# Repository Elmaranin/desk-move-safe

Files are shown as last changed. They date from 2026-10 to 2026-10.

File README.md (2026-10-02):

# table-controller

A standing desk with a folding flap on it. The flap has to be moved out of the
way at a particular height, so something has to notice the desk approaching
that height and stop it there.

The desk is a **Völundr X2DM-SE** with a **CL103B-G** control board. Its panel
talks to that board over a 4-wire UART, and the whole project rests on having
worked out what they say to each other.

```
docs/                 what was learned — protocol, wiring, roadmap, photos
desk-move-safe/       PRODUCTION firmware. The one job, small console
usb-uart-tools/       Python that drives the desk from a laptop, no MCU
3d-models/            printed parts
```

## Where to start

| you want to | read |
|---|---|
| build and install the thing | [desk-move-safe/README.md](desk-move-safe/README.md) |
| wire it up | [docs/wiring.md](docs/wiring.md) |
| understand the desk's protocol | [docs/CL103B-G_protocol.md](docs/CL103B-G_protocol.md) |
| try something without flashing | [usb-uart-tools/README.md](usb-uart-tools/README.md) |
| know what is next | [docs/roadmap.md](docs/roadmap.md) |

## The two traps

**The panel header's `RX`/`TX` labels are swapped.** The pin marked `RX` is the
one the panel transmits on. Trust them and both leads land on the wrong pins,
and the failure is silent in both directions while the desk carries on working.

**A board that is not proxying is a desk that cannot move.** The panel-TX wire
is cut, so everything the main board hears comes from the firmware. That is
why proxying is on at boot — and why the failure mode is a stationary desk
rather than a runaway one.

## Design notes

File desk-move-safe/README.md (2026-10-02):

# desk-move-safe

Production firmware. Keeps a standing desk from carrying a folding flap past
the height the flap has to be moved at.

It sits in the cut panel-TX wire between the desk's control panel and its
CL103B-G main board, and forwards both directions. **The panel drives the desk
exactly as it did before.** When a move would take the desk past the flap
height, this takes the bus, stops it there, runs the flap, and lets the move
finish.

For the bench rig this was worked out on — frame tracing, raw byte dumps,
cadence and coast measurement, manual injection, panel emulation — see
desk-lab, which is kept locally and not published. None of that is here.

## Documentation

- [../docs/wiring.md](../docs/wiring.md) — board, pin map, **what to cut**
- [../docs/CL103B-G_protocol.md](../docs/CL103B-G_protocol.md) — the desk protocol
- [docs/operation.md](docs/operation.md) — what it does at the desk, modes, bring-up
- [docs/commands.md](docs/commands.md) — **every console command**, and every stored parameter

## Build

Needs **Pico SDK 2.2.0** under `~/.pico-sdk` (what the Raspberry Pi Pico VS Code
extension installs) and a **FreeRTOS-Kernel** checkout pointed at by
`FREERTOS_KERNEL_PATH` (`build.sh` carries a default).

```sh
./build.sh          # -> build/desk-move-safe.uf2
./flash.sh          # build + flash over USB, no BOOTSEL button
./flash.sh -n       # flash what is already built
```

The first flash onto a board running unrelated firmware needs one BOOTSEL
press; every flash after that is button-free.

## Two things that will bite

**The panel header's `RX`/`TX` labels are swapped** — the pin marked `RX` is
the one the panel transmits on. Both leads end up on the wrong pins if you
trust them, and the failure is silent in both directions while the desk keeps
working normally. [../docs/wiring.md](../docs/wiring.md) has the photograph.

**A board that is not proxying is a desk that cannot move.** The wire is cut,
so everything the board hears comes from here. That is why proxying is on at
boot and cannot be switched off from the console, and why the failure mode is
a stationary desk rather than a runaway one.

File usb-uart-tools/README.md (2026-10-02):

# usb-uart-tools — driving the desk from a laptop

Python that talks to the desk's bus through a **USB-UART adapter**, with no
microcontroller involved. This is where the protocol work started, and it is
still the quickest way to try something without flashing anything.

The panel is unplugged and the adapter takes its place:

```
  adapter TX --[1k]--> board RX     (we send the poll and the key frames)
  adapter RX <-------- board TX     (we read the height)
  GND ---------------- GND          3.3 V logic, 9600 8N1
```

Mind the panel header's labels — `RX` and `TX` on it are swapped relative to
the panel's own role. [docs/wiring.md](../docs/wiring.md) has the detail.

| script | what it does |
|---|---|
| `poll_test.py` | streams the idle poll and prints the height. The "is anything alive" test |
| `desk_goto.py` | closed-loop positioning: `./desk_goto.py 73cm`, `--sit`, `--stand`, `--save-sit` |
| `tmc_test.py` | one UART read to the stepper driver, decoded. `--scan` tries all four node addresses. Verified against a real TMC2209 |

`tmc_test.py` talks to the **stepper driver**, not the desk, and wants its own
wiring — 115200 8N1, and the driver has a single UART pad so it is half duplex:

```
  adapter TX --[1k]--> PDN_UART     the resistor is not optional
  adapter RX <-------- PDN_UART     the same pad, directly
  GND ---------------- GND
```

You will see your own request echoed before the reply, because RX sits on the
pad we transmit into. That echo is the point: no echo means the fault is at our
end, an echo with no reply means the driver is silent, and those need completely
different fixes.

Both take `--port`; edit `CMD_PORT` at the top of `desk_goto.py` for a default.
Protocol reference: [docs/CL103B-G_protocol.md](../docs/CL103B-G_protocol.md).

> `desk_goto.py` predates most of what is now known about this desk — in
> particular that a single edge frame is a 10 mm step, and that a recall must
> be sent as exactly ONE frame. Its `preset()` streams three, which is why it
> could save presets but never recall one. Read the protocol doc before
> trusting its timings.

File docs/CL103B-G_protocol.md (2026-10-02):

# Volundr X2DM-SE — CL103B-G Controller Protocol

Complete reverse-engineered protocol for the desk control board, verified by bus
capture. Everything here was confirmed empirically during analysis, not assumed.

**Board:** `DSK_CL103B_Main_V1.2`
**MCU:** Nations Technologies N32G031 (Cortex-M0, 3.3 V, STM32-compatible SWD)
**Panel link:** detachable control panel ↔ main board over UART

---

## 1. Physical link

- **UART, 9600 baud, 8N1, 3.3 V logic.**
- 4-pin header labelled (from the panel's viewpoint) `3.3V RX TX GND`.
- The panel is the *polling master* in normal use: it sends a request every
  poll tick; the board answers with status/height.
- **Panel poll cadence: ~104 ms** (measured 102–106 ms, ≈9.6 Hz, very stable).
  A second desk measured 103–105 ms steady, with single gaps stretching to
  115 ms around a button press — the panel's key scan costs it a few ms.
  Anything replacing the panel should poll at this rate, not faster.
- Board streams height in response to being polled — by the real panel OR by any
  device that sends the poll frames. With the panel removed, a controller that
  streams the idle poll keeps the board reporting height normally.
- **Stop polling and it stops answering.** This makes silence a bad way to stop
  the desk: it takes the height stream down with it, and a reading that has
  stopped changing is indistinguishable from a desk that has stopped moving.
  Anything that needs to watch the desk must keep sending the idle poll —
  which is equally "no command" for a held move, and costs nothing.

### Header notes (this board)
- A separate 5-pin black header is the **SWD debug port** (SWDIO/SWCLK/NRST/3V3/GND),
  not a UART. Serial attempts on it see nothing — expected; SWD is silent until a
  debugger drives it.
- The `3.3V RX TX GND` header is the panel UART used throughout this document.

### ⚠️ The board's power output is switched off while the desk moves

Measured 2026-10-02: the controller board's power output port loses its voltage
for as long as the desk's motors run, and gets it back when they stop. It is not
a tap on the supply input. Anything that has to work *during* a move must not
be powered from it — see [wiring.md](wiring.md#power).

### ⚠️ The panel header's RX and TX labels are SWAPPED

Photographed on the panel PCB of this desk (`docs/desk/2026-09-22 10-57-31.JPG`):

```
   3.3V    RX      TX     GND      <- silkscreen on the PANEL
            |       |
            |       └── the panel RECEIVES here (board -> panel, height)
            └────────── the panel TRANSMITS here (panel -> board, keys)
```

So the labels name the **main board's** role, not the panel's. The pin marked
`RX` is the one the panel drives.

The main board's own header is labelled by function and is not swapped
(`docs/desk/2026-09-22 10-56-03.JPG`): `TX to panel`, `RX from panel`.

The practical consequence, and it is the trap that costs an evening:

| you want to | use the panel pin marked |
|---|---|
| **listen** to the panel's key frames | `RX` |
| **drive** the main board (replace the panel) | `RX` |
| **listen** to the board's height frames | `TX` |
| **drive** the panel's display | `TX` |

Assuming the labels are from the panel's viewpoint puts both leads on the
wrong pins at once. The failure is silent in both directions — the input
landing on an output pin is fought and never received, the output landing on
an input pin drives nothing — while the panel and board carry on over the
wires that are still intact. The desk keeps working, and nothing is heard.

---

## 2. Frame format (both directions)

```
[ sync0 sync1 ] [ len ] [ type ] [ payload... ] [ cksum_hi cksum_lo ]
     2 bytes       1        1        variable          2 bytes
```

- **Sync encodes direction:**
  - `55 AA` = **main board → panel** (status / height)
  - `AA 55` = **panel → main board** (key reports / commands)
- **len** = total frame length in bytes = `0x08` for all frames observed.
- **type** = message id (`0x02` = height report; `0x01` = key report).
- **checksum** = 16-bit **big-endian sum of ALL preceding bytes**, sync included.

Verify / generate:

```python
def cksum_ok(f):                      # f = 8-byte frame
    s = sum(f[0:6])
    return (s >> 8) == f[6] and (s & 0xFF) == f[7]
```

Both directions use identical 8-byte framing.

---

## 3. Board → panel : height report  (`55 AA`, type 0x02)

```
55 AA 08 02  HH HL  CK CK
             └──┬─┘
     14 bits of millimetres, big-endian, with FLAGS in the top 2 bits
```

**The height field is not a plain u16.** Captured while saving a preset,
checksum valid:

```text
 121.989  105.0  board 55 AA 08 02 42 F5 02 40   0x42F5 = 17141 "mm"
```

`0x42F5 & 0x3FFF` = **757**, which was exactly the desk's height at that
moment. Bit 14 is a flag the board raises around a save — most likely the
"stored / beeping" acknowledgement, since it appeared only while save codes
were going out and cleared afterwards. Bit 15 has never been observed set.

Mask with `0x3FFF` before believing a height. Reading the field raw is not a
cosmetic bug: 17141 mm handed to a closed-loop move is a desk being told it is
sixteen metres too high, and the correction is downward and fast.

- Example: `55 AA 08 02 02 CC 01 D7` → 0x02CC = 716 = **71.6 cm**
  (checksum 55+AA+08+02+02+CC = 0x01D7 ✓).
- Streamed continuously; repeats the same frame while stationary.
- During motion, roughly one frame per mm of travel.
- Display truncates to whole cm; the bus carries full mm resolution.

### Motion characteristics
- **Down is faster than up.** Descending ≈ 2–3 mm/frame; ascending ≈ 1 mm/frame
  (gravity assists the motors). Size any timing margins against the *down* speed.
- **Post-command coast:** after the last motion command the desk keeps moving
  briefly in its direction of travel — roughly 8–15 mm depending on run length
  and load. Open-loop stops must aim short; closed-loop must re-read and settle.

### Target announcement (preset pre-move)
Before an autonomous preset move, the board briefly emits height frames carrying
the **target** value (a static height differing from current) before it starts
driving. Gives ~1 s of look-ahead: you can know the destination before motion.

Captured on an RP2350 emulating the panel, after a one-frame `0x01`:

```text
   0.000       -  board 55 AA 08 02 02 E6 01 F1  height 742 mm   <- resting
                  board  ... x50 more over 5.1 s
   5.310   110.0  board 55 AA 08 02 03 08 01 14  height 776 mm   <- TARGET
                  board  ... x9 more over 0.8 s
   6.340   100.0  board 55 AA 08 02 02 E8 01 F3  height 744 mm   <- real, climbing
   6.450   110.0  board 55 AA 08 02 02 E9 01 F4  height 745 mm
```

Three things this pins down:

- The **target is announced for ~0.8–1.0 s** as a static value, then the
  stream reverts to the real height and the desk starts moving.
- **It arrives as a jump no desk could make.** Captured with the real panel:
  the desk sitting at 743 mm, one frame later the stream says 803, a second
  after that 745 and climbing for real. That +60 mm in a single frame is how
  the announcement is told apart from motion — real travel is 2–3 mm per frame
  descending and 1 ascending, so anything past about 10 mm did not happen
  mechanically. Filter on that and the announcement stops being a hazard and
  becomes the longest look-ahead this bus offers.
- Treating it as a height is briefly wrong by six centimetres: direction flips
  twice, a ceiling check thinks the desk is above the limit, and an intercept
  computes its trigger against a height the desk never occupied.
- The board sat at 742 mm for **5.3 s after the command** before announcing
  anything. A recall is not refused quickly — "nothing happened yet" needs
  several seconds of patience before it means "ignored".
- Height then advances ~1 mm per frame climbing, matching the "up is slow"
  note above.

---

## 4. Panel → board : key report  (`AA 55`, type 0x01)

```
AA 55 08 01 00  KK  CK CK
                └┬┘
              key code (byte 5; byte 4 always 00)
```

### Confirmed code table

| Code | Action | Behaviour |
|---|---|---|
| 0x00 | idle / no key | streamed constantly as poll / keep-alive |
| 0x01 | recall **stand** | one-shot; board self-drives to stored height |
| 0x02 | recall **sit** | one-shot; board self-drives to stored height |
| 0x03 | save **stand** | store current height → stand slot (5 s button hold) |
| 0x04 | save **sit** | store current height → sit slot (5 s button hold) |
| 0x05 | **down** step | one frame = -10 mm; also the press edge of 0x06 |
| 0x06 | **down**, held | must repeat every poll tick to keep moving |
| 0x07 | **up** step | one frame = +10 mm; also the press edge of 0x08 |
| 0x08 | **up**, held | must repeat every poll tick to keep moving |
| 0x0E | panel **wake** | panel coming out of sleep, as its display lights up |

### A single edge frame is a 10 mm STEP command

`0x05` and `0x07` are not markers. One frame of either, with nothing else sent
before or after, moves the desk a fixed distance. Measured on an RP2350 in the
panel-TX path, injecting exactly one frame into the stream from a standstill:

```text
  79.919   ours AA 55 08 01 00 07 01 0F  key up edge     <- one frame
  80.024   ours AA 55 08 01 00 00 01 08  key idle
  80.679  board 55 AA 08 02 02 F2 01 FD  height 754 mm   <- 0.76 s later
   ...     1 mm per frame for 1.03 s ...
  81.709  board 55 AA 08 02 02 FB 02 06  height 763 mm   <- +10 mm exactly
```

| | up (`0x07`) | down (`0x05`) |
|---|---|---|
| travel | **+10 mm** | **−10 mm** |
| latency before motion | 0.76 s | 0.75 s |
| rate during the step | 1 mm/frame | 1 mm/frame |

Symmetric in both directions, unlike a held move, where down runs 2–3 mm/frame
against up's 1. This is the panel's fine-adjust: a tap of the button steps a
centimetre.

**Consequences for anything driving this bus:**

- **A tap is never free.** Sending an edge code to "interrupt" something costs
  a centimetre of travel in that direction. Interrupting a descent with a Down
  tap asks the desk to descend another centimetre.
- **0.75 s of latency before anything happens**, which is around seven poll
  frames. Code that sends a tap and looks for movement on the next frame will
  conclude it was ignored.
- **It is a precise positioning primitive.** Ten millimetres, repeatable, no
  coast to allow for — the creep phase of a closed-loop move can use taps
  instead of timed pulses.

### The motion codes are two pairs, edge then held

```text
        edge   held
down    0x05   0x06
up      0x07   0x08
```

Both edge codes were confirmed by hand on an RP2350 tap: a single Down tap
gives `0x05`, a single Up tap gives `0x07`. That closes out the older reading
of `0x07` as an "up transient, exact meaning not pinned down" — earlier
captures only ever caught it at press edges during a held move, so it looked
like a side effect rather than a code in its own right. Read the group as
`0x05..0x08` = {down, up} x {edge, held} and nothing in it is unexplained.

Consequence for anything that watches the bus: **a tap can move the desk
without a held code ever appearing.** Logic that treats only `0x06`/`0x08` as
"the user is driving the desk" misses short presses entirely.

### 0x0E — panel wake

Emitted by the panel as it comes out of sleep and starts displaying a height,
not in response to a button. Not yet known whether the board requires it, or
merely tolerates it, before it will answer polls — which matters for
panel-free operation (§6): a controller replacing the panel may need to send
it once at startup. Untested.

### Prebuilt frames (checksums verified)

```
idle        AA 55 08 01 00 00 01 08
recall stand AA 55 08 01 00 01 01 09
recall sit   AA 55 08 01 00 02 01 0A
save stand   AA 55 08 01 00 03 01 0B     # overwrites stored stand height
save sit     AA 55 08 01 00 04 01 0C     # overwrites stored sit height
down edge    AA 55 08 01 00 05 01 0D
down (hold)  AA 55 08 01 00 06 01 0E
up   edge    AA 55 08 01 00 07 01 0F
up   (hold)  AA 55 08 01 00 08 01 10
panel wake   AA 55 08 01 00 0E 01 16
```

Note the trap in that list: the *checksum low byte* of `down (hold)` is `0E`,
the same value as the `panel wake` **key code**. A key code of `0x0E` read out
of a misaligned parse would look identical to a real panel-wake frame. The
checksum is what tells them apart, so validate it before believing any code —
`AA 55 08 01 00 0E 01 16` is a wake, and anything else ending in `0E` is not.

### Behaviour notes
- **Up / Down are HELD commands:** motion continues only while the code streams
  at the poll cadence; revert to idle (0x00) or stop sending to halt.
- **Recall presets (0x01/0x02) are one-shot, and "once" means ONE FRAME.**
  Captured from a real panel on an RP2350 tap:

  ```text
     0.000       -  panel AA 55 08 01 00 00 01 08  key idle
                    panel  ... x58 more over 5.9 s
     6.160   115.0  panel AA 55 08 01 00 01 01 09  key recall stand
     6.265   105.0  panel AA 55 08 01 00 00 01 08  key idle
  ```

  A press of the stand button puts `0x01` on the wire for exactly one frame,
  and the next poll 105 ms later is already idle. Same for sit. No edge code
  precedes it — unlike up/down, the preset buttons emit a single code — and no
  `0x0E` is involved.

  **This is the thing to get right when emulating the panel.** A controller
  that streams the recall code for several frames is not sending a tap, it is
  holding the button, and a held preset button is the *save* gesture on this
  panel. A laptop script that streamed it for three frames could save presets
  but could never recall one.

  **A single edge frame aborts an in-progress preset.** Captured end to end: a
  stand recall heading for 803 mm, one `0x07` frame injected at 749 mm, and the
  desk stopped at 764 and stayed — 39 mm short of its target. One frame is
  enough; it does not have to be held.

  The abort is not instant. From 749 the desk travelled 15 mm over 3 s,
  decelerating — visible as the height repeating each value more often as it
  slows. Size any stop-short margin against that 15 mm, not against zero.

  So autonomous moves are both *suppressible* (don't forward 0x01/0x02) and
  *interruptible* (one injected edge frame).
- **Save (0x03/0x04) is ONE FRAME, like recall.** The ~5 s button hold is a
  *panel-side* gesture: the panel times the press locally and puts a single
  save code on the wire at the end of it. How long the button was held never
  appears on the bus.

  A controller that streams the save code for five seconds instead sends ~48
  save commands, and the board stores and beeps for a good number of them —
  measured at about ten beeps for one intended save. The board beeps once per
  save it accepts, so **more than one beep means more than one frame.**

  This is the same rule that governs recall, learned twice: **the panel emits
  one-shot codes exactly once.**
- **0x07** appears at the start/edge of up-presses (a tap transient). The reliable
  motion codes are the *held* values 0x06 / 0x08; treat 0x07 as an edge marker.

### Recall drive speed (important for tracking completion)
A recall self-drives at the normal motion speed — **upward is slow (~1 mm/frame)**.
Code that waits for a recall to finish must require *sustained* stability (≥ ~2 s
of no change) after motion is seen, or a brief plateau during the slow climb can
be mistaken for arrival.

---

## 5. Electrical / tapping rules

- 3.3 V logic. The header's `3.3V` pin is **power, not signal level** — never feed
  it into a signal line; use a 3.3 V USB-UART adapter.
- **Listen-only tapping:** input pins only. Do not drive a line the panel or board
  is already driving — two push-pull outputs on one wire corrupt frames and can
  freeze the panel (observed).
- Put a **1 k–10 k series resistor** in every probe / inject lead. Reads fine at
  9600 baud but prevents a short or drive-fight from disturbing the bus.
- **To inject commands you must be the sole driver of the board's RX line:**
  either remove the panel (replace it), or man-in-the-middle it (cut the panel's
  TX so it reaches only your controller's RX; your controller's TX drives the
  board). Do not inject while the panel is still wired straight to the board.
- Single-adapter software must **serialize port access** (one lock guarding read
  and write); concurrent read+write on one pyserial port raises "device reports
  readiness to read but returned no data" on macOS.
- Power the controller from ONE supply (its own USB, or the board's 5 V — not both);
  share ground.

---

## 6. Panel-free operation (replace the panel)

Confirmed working: a controller that streams the idle poll keeps the board
reporting height, so the panel is not required.

- **Poll continuously at ~104 ms** with the idle frame so height keeps flowing.
- To move: stream UP / DOWN at the poll cadence; stop by reverting to idle.
- To recall: send the one-shot recall frame, then track the self-driven move.
- Reading height back and closed-loop positioning both work with the panel absent.

---

## 7. Duty cycle, sleep, and the other things the manual documents

From the Völundr X2DM-SE manual (`docs/desk/2026-07-07 18-11-27.JPG` and
`18-11-37.JPG`). None of this is on the bus, but all of it changes how the bus
behaves.

### Thermal protection
**4 minutes of continuous running inside an 18-minute window** trips it — not
the "2 min on / 18 min off" estimated earlier. The display shows `HOT`, every
panel function is blocked and the buttons stop responding. It clears by itself
after 18 minutes, or on a power cycle. A lockout refuses the physical panel
too, which is how it is told apart from a logic bug.

### Energy-saving mode — and it ignores movement
After **30 seconds with no button press** the panel's display goes dark and the
controller drops to low power. Any button wakes it. The manual is explicit:

> **In energy-saving mode, movement commands are not executed.**

This matters for anything driving the bus. A controller that has been streaming
idle polls for a while and then sends a move may have that move ignored, with
the frame serving only to wake the desk. It is the most likely explanation for
the **~0.75–1.0 s** measured between an injected step frame and any movement
(§4) — the first frame wakes, the desk acts after. Untested: whether idle poll
frames count as activity and hold sleep off, or whether only key codes do.

**A move injected toward the board does not wake the panel's display.**
Observed 2026-10-02 with desk-move-safe's `go`: the desk moved and the board
kept sending height frames on the uncut height wire, but a sleeping panel stayed
dark throughout. Woken by one of its own buttons first, it followed the move
correctly. The panel's sleep is decided by the panel's own key presses; nothing
sent to the board changes it. Waking it from firmware would mean driving the
panel's `TX`-marked pin, which needs that wire cut first.

### Child lock
`stand + sit + ▲` held 5 s shows `LOC` and blocks raise/lower;
`stand + sit + ▼` held 5 s releases it. Worth knowing before concluding the
desk is ignoring the bus.

### Error codes
On error: 2 beeps, then lockout; 2 beeps again when it clears.

| | | | |
|---|---|---|---|
| `E01` motor 1 open | `E02` motor 2 open | `E03` motor 1 overload | `E04` motor 2 overload |
| `E05` motor 1 Hall unplugged | `E06` motor 2 Hall unplugged | `E08` obstacle detected | `E09` large position discrepancy |
| `E10` high voltage | `E11` low voltage | `E12` motor 1 Hall open | `E13` motor 2 Hall open |
| `E14` overload protection | | | |

Most clear with the Down button held 5 s, or a power cycle. Whether any of
these appear on the UART is not known — the height field's flag bits (§2) are
the obvious place to look.

## 8. Settings menu (P00–P06) — what can be changed in the desk itself

Hold `▼ + ▲` for 5 s to enter. `▲`/`▼` steps through P00…P06, the **stand**
button enters and confirms a parameter, and 5 s of inactivity saves and exits.

| Menu | Param | Range | Default | Notes |
|---|---|---|---|---|
| Units | `P00` | 0/1 | 0 | 0 = cm, 1 = inches |
| Min height | `P01` | 73 cm … (P02−10) | 73 cm | 1 cm steps |
| Max height | `P02` | (P01+10) … 122 cm | 122 cm | 1 cm steps |
| Tabletop thickness | `P03` | 0.0 … 10.0 cm | 0.0 | offsets the displayed height |
| Rise sensitivity | `P04` | 0–10 | 5 | obstacle protection; 0 = off, **higher number = less sensitive** |
| Descent sensitivity | `P05` | 0–10 | 5 | as P04 |
| **Buzzer** | `P06` | 0/1 | 1 | **0 = off except alarms** |

Three of these are directly useful to a project that drives the bus:

- **`P06 = 0` silences the beep.** The desk beeps once per one-shot code it
  accepts, which is unavoidable on the wire — but it does not have to be
  audible. Alarms still sound.
- **`P01`/`P02` are the desk's own travel limits**, and they are what
  `DESK_MIN_MM` / `DESK_MAX_MM` should mirror. Defaults are 730–1220 mm.
- **`P03` shifts the displayed height.** If it is non-zero, the number on the
  bus and the physical height of the top differ by that much. It was 0.0 on
  this desk.

### Confirmed: a short press is 10 mm

The manual states it outright — short press on `▲`/`▼` raises or lowers by
**10 mm**, long press moves continuously. That is the same 10 mm measured on
the wire for a single `0x07`/`0x05` frame (§4), from the other direction.

### Reset / calibration
Needed if the displayed height stops matching reality, or a leg is replaced.
Hold `▼` 5 s → display shows `RST`; press `▼` again to run it. The desk drives
to its lowest point, rises 10 mm, beeps, and shows the minimum height.

---

## 8. Positioning approach (open-loop coast → closed-loop creep)

Because of post-command coast, reliable positioning uses two phases:

1. **Coarse:** drive fast toward the target, stop short by the coast distance
   (~15 mm) so momentum carries in. Skip this phase entirely if the move is
   smaller than the coast distance (otherwise the desk overshoots or no-ops).
2. **Creep:** short pulses (≥ ~2 poll periods each ≈ 0.22 s) with a re-read
   between each, approaching at near-zero speed until within a few mm. No coast;
   works for moves of any size and cleans up the final error.

Report the settled height only after the desk is stably quiet, and take a final
fresh reading so it matches what the next command will see (accounts for coast).

### Key parameters (this desk)
- Poll / command cadence: **0.104 s**
- Coast allowance: **~15 mm** each direction (tune per run length)
- Creep pulse: **~0.22 s** (≥ 2 poll periods)
- Settle: require ~1.2 s continuous no-change; presets need ≥ 2 s after motion

---

## 9. Complete command summary (copy-paste)

```
Link:   9600 8N1, 3.3V, poll every ~104 ms
Frame:  55AA/AA55 | 08 len | type | payload | 16-bit BE sum over all prior bytes

Board→panel (55 AA):
  type 0x02  height = u16 BE mm

Panel→board (AA 55, type 0x01, code in byte 5):
  0x00 idle      0x01 recall stand   0x02 recall sit
  0x03 save stand 0x04 save sit
  0x05 down edge  0x06 down(held)     0x07 up edge   0x08 up(held)
  0x0E panel wake

Prebuilt AA 55 frames:
  idle  aa5508010000 0108      recall stand aa5508010001 0109
  recall sit aa5508010002 010a save stand aa5508010003 010b
  save sit  aa5508010004 010c
  down  aa5508010006 010e      up  aa5508010008 0110
  down edge aa5508010005 010d  up edge aa5508010007 010f
  panel wake aa550801000e 0116
```

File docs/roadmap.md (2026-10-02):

# Roadmap

Where this rig is going, and what each step has to prove before the next one is
worth starting.

## Phase 0 — done, on other hardware

- The desk protocol is reverse-engineered and bus-verified:
  [CL103B-G_protocol.md](CL103B-G_protocol.md). Framing, height reports, the
  full key-code table, injection rules, panel-free operation.
- Stepper and MT6835 encoder are proven on the bench rig at
  `../test/nema_MT6835`: motion profile, measured gearbox ratio, lost-step
  detection, encoder-defined travel limits.
- The sniffer firmware exists and is listen-only by construction.

What is *not* proven: the stepper and the encoder on the RP2350 Supermini, and
the flap against the real desk.

## Phase 1 — listen, and move the flap

*Bus half done, flap half not started.* The taps work against the real desk:
height and keys decode, the trace and the `bus` measurements run. The stepper
has not been wired to this board yet, so steps 3–5 below are still open, and
the timing question they answer is still open with them.

Wire the taps and the driver per [wiring.md](wiring.md); leave the encoder
unfitted. The desk keeps its panel and stays in charge throughout.

**Steps**

1. Ground tap + board tap only. `p` shows a live height; `w` streams it while
   the desk moves. Nothing else matters until this works.
2. Add the panel tap. Press keys, watch them decode.
3. Add the driver with the motor *uncoupled*. `home`, then `x` / `c` by hand.
4. Couple the flap. Find the real hysteresis band with `th` + `w`, then bake it
   into `FLAP_EXPAND_BELOW_MM` / `FLAP_COLLAPSE_ABOVE_MM`.
5. `auto on`, and drive the desk around for a while.

**The measurement that decides phase 2.** On the numbers currently in
`board_config.h` a full flap swing is about **2 s** — 90° of output through
48.435:1 at 1/8 microstepping is 19 400 microsteps, and at 10 000 steps/s that
is 1.94 s plus the ramp. The desk descends at roughly 25 mm/s and coasts 8–15 mm
after the last command. So by the time the flap has finished moving, the desk
has travelled something like **50 mm** past the height that triggered it, plus
coast.

(Confirm the ratio first: `GEAR_RATIO` here is 48.435, the *old* gearbox. The
bench rig now runs 17.23:1, which would cut the swing to ~0.7 s and the margin
to ~20 mm. Which box is on the flap changes the answer by a factor of three, so
measure before trusting either number.)

That number is the whole question. Time the flap and the desk for real, then:

- If the threshold can lead the collision point by that margin and still sit
  inside the desk's useful range — **listening is enough, and phase 2 is
  optional.** Preset recalls even announce their target about a second ahead
  (protocol §3), which buys more lead than a manual hold does.
- If the margin does not fit, the flap has to be able to *stop the desk*, which
  is phase 2.

**Exit criteria:** height decodes with no checksum errors over a long run, the
flap tracks the band without oscillating, and the timing above is a measured
number rather than an estimate.

## Phase 2a — replace the panel  — **done and working**

Panel unplugged, RP2350 in its place: `emul on` streams the poll at 104 ms and
the board reports height with no panel attached. `go`, `sit`, `stand`, `save`
and raw `key` all work. No rewiring was needed — GP5 is the panel tap while
sniffing and a PIO transmitter while emulating, because the wire the board
listens on is the wire the panel used to drive.

Four things the real desk taught us here, all now in
[the protocol doc](CL103B-G_protocol.md):

- **One-shot codes are sent exactly once.** One frame for a recall, one for a
  save. The panel's press durations — a tap, a five-second hold — are timed
  *inside the panel* and never reach the bus. Streaming a recall for three
  frames is why a laptop script could save presets but never recall one;
  streaming a save for five seconds stores it about ten times.
- **The height field is 14 bits plus flags.** Bit 14 is raised around a save.
  Read raw, it reports a 17-metre desk, which a closed-loop move would try
  hard to correct.
- **`0x05`/`0x07` are the down/up press edges**, completing the motion group.
- **A recall takes its time**: ~5 s before the board reacts at all, then ~1 s
  announcing the target as a static height before it starts driving.

## Phase 2b — man in the middle: **ruled out**

Splitting the panel's TX from the board's RX needs a break in that wire, and
on this desk the header cannot be passed through — there is no way to get
between the panel and the board without cutting. So a true MITM is off the
table, and with it the ability to *suppress* what the panel sends.

**Frame-gap injection does not rescue it either.** The idea — transmit in the
~95 ms the line sits idle between panel frames — is sound in timing and wrong
in electronics. The panel's TX is push-pull and actively drives the line high
when idle. Sinking against it gives a divider of roughly equal output
impedances, so the line lands near 1.6 V: not a valid logic low, so the board
does not read our bits, while both output stages pass tens of milliamps. There
is no series resistor that fixes this — one large enough to be safe makes the
panel win by more.

Either the wire is broken or we cannot talk over the panel. Those are the only
two states.

### What replaces it

Nothing needs to. The two jobs the flap actually has are both reachable
without cutting:

**Knowing early.** Three lead-time signals are already on the taps, passively:

| Signal | Lead time |
|---|---|
| a key frame (`0x05`/`0x06` down, `0x07`/`0x08` up) | the instant the user presses, before the height has moved |
| a preset recall's target announcement | ~5 s of board silence, then ~1 s of announced target, before motion |
| the height stream itself | continuous, ~1 mm per frame |

The flap currently waits for the *height* to cross a threshold, which is the
last and latest of the three. Triggering on intent instead is a firmware
change and buys back most of the swing time.

**Not needing to stop the desk.** Phase 2a already proved the RP2350 can *be*
the panel. With the panel unplugged for good, the desk only ever moves when we
tell it to — so the flap goes first and the desk follows, and there is nothing
to stop. The cost is the physical buttons, which GP12–GP15 and GP26–GP29 are
free to replace.

Cutting one wire stays available as the fallback, and is genuinely small — but
it should be the answer only after the timing measurement in phase 1 says the
lead time above is not enough.

## Phase 3 — close the flap loop with the encoder

Fit the MT6835 on GP8–GP11 and port `task_encoder.c` / `limits.c` from the
bench rig.

This is what makes the limit switch redundant: the MT6835 is absolute, so the
flap knows where it is at power-on with no homing sweep at all. Travel ends
become stored angles (`lim min` / `lim max`) instead of a switch, and a stall
becomes a number instead of silence — open-loop step/dir emits the same pulses
whether or not the motor followed them.

Bring the gearbox ratio over by *measuring* it with `cal`, not by copying
`GEAR_RATIO`: the bench rig's box measured 17.23:1 and the one before it,
sold as "50:1", measured 48.435:1.

**Exit criteria:** no homing sweep at boot, position correct after a power
cycle, and a deliberately jammed flap reports lost steps instead of silently
drifting.

## Phase 4 — permanent install

- Power from a 24 V → 5 V buck into the `5V` pad, USB disconnected — see the
  power section in [wiring.md](wiring.md) about not doing both at once.
- The onboard WS2812 on GP16 becomes the status light: height streaming,
  height stale, flap moving, fault.
- Connectors and strain relief on the desk tap. A tap that falls off mid-move
  is the failure mode most likely to happen twice.
- Enclosure, and the 3D-printed parts in `3d-models/`.

## Deliberately not planned

- **TMC2209 UART.** Both hardware UARTs belong to the desk; the driver's UART
  would have to be a PIO one. Worth it only if software current control or
  StallGuard turns out to be needed, and phase 3 makes StallGuard largely
  redundant.
- **Driving the desk to positions.** `usb-uart-tools/desk_goto.py` already does
  closed-loop positioning from a laptop. Putting it in the firmware is a
  different project from "flap follows desk".

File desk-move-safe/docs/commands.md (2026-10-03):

# Console commands

The complete command reference for the USB console (USB CDC; any terminal).
`?` prints the short form on the board.

> **Kept in sync by the build.** Every command `help()` prints in
> [`../src/console.c`](../src/console.c) must have a row in the command tables
> below, with the same signature, and every parameter in
> [`../src/params.c`](../src/params.c) must have a row in
> [Stored parameters](#stored-parameters) — and nothing may be documented that
> no longer exists. [`../tools/check_commands.sh`](../tools/check_commands.sh)
> runs at the start of `./build.sh` and fails the build on any difference.

## How the console is laid out

A few words at the top level. Everything else sits under a **group word** —
`desk`, `debug`, `lim`, `mot`, `tmc`, `enc` — and every stored value is read and
changed with **`eeprom`**. A group word on its own prints that group's state.

**Mode** says where a command works. *working* commands are available after
every reboot. *dev* commands need `dev start` first; they drive something
directly, poke a register or change the flap's stored range. See
[operation.md](operation.md#working-mode-and-dev-mode).

## Top level

| Command | Mode | What it does |
|---|---|---|
| `status` | working | Everything at a glance: the self-check (mode, driver, encoder, limits, and whether the desk is locked), then what `desk` prints, whether the settings came from flash, and the motor's state. Printed at boot too. |
| `calibrate` | working | Calibrate the flap, step by step: clears the calibration (what `reset` clears), then asks for the flap at its expanded end and at its collapsed end and stores each on `done`. Unlocks `mot` and `enc` while it runs. See [Calibrating](#calibrating). |
| `done` | working | During `calibrate`: store the position the flap is at now, and go on to the next step. |
| `abort` | working | During `calibrate`: leave it. The calibration stays cleared, so the desk stays locked until `calibrate` is run to the end. |
| `reset` | working | Clear the **flap calibration** — exactly the parameters the desk and the motor need to move (see [What it needs to move](#what-it-needs-to-move)) — and nothing else. Afterwards the desk is locked and the motor only jogs until the flap is calibrated again — `calibrate` does that. Presets, coast, the flap height, backlash and approach are kept. Not to be confused with resetting the board, which clears no parameter. |
| `stop` | working | Stop whatever the firmware is driving, now: a `go`, a flap takeover, the flap motor. |
| `dev` | working | Working or dev mode, and the boot self-check, repeated. |
| `dev start\|stop` | working | Unlock the dev commands, or lock them again. Dev mode suspends the flap intercept; leaving it stops and releases the motor. Never stored: every reboot comes up in working mode. |
| `eeprom` | working | Every stored parameter with its value and unit, grouped by section. The first line says whether RAM matches flash, has a change waiting to be written, or nothing is stored yet. |
| `eeprom <name>` | working | One parameter, e.g. `eeprom desk_flap_mm`. |
| `eeprom set <name> <value>` | working | Change one parameter, in its stored unit (mm, not cm). Validated by the module that owns it; written to flash once the desk and the motor have been still for a few seconds. `lim_*`, `mot_*` and `desk_resume_pct` need dev mode, and the measured ones are read-only — the reply names the command that sets them. |
| `?` | working | The short command list. |
| `go <cm>` | dev | Drive the desk to a height, bypassing the panel. Refused while the desk is locked (see [What it needs to move](#what-it-needs-to-move)). From far away it drives and releases a coast early; within a coast of the target, where a drive would overshoot, it steps up or down with 10 mm taps until it is within 10 mm. Panel buttons are ignored during the move; `stop` ends it. `go` does not move the flap: a target above the flap height is refused while the flap is not collapsed. |

## desk — the desk side

| Command | Mode | What it does |
|---|---|---|
| `desk` | working | Live height, bus frame counts, what the firmware is doing, the flap stop (height, on/off), the ceiling, the presets and the coast. |
| `desk ceiling [on\|off]` | working | Replace UP with idle near `DESK_CEILING_MM`, whatever the panel asks: a held UP a coast early, a tap only if its 10 mm step would end past the ceiling. Says so (`[desk] UP refused …`) and blinks red. Preset recalls are not checked. Not stored: on at every boot. |

The desk's stored values — presets, coast, flap height and switch — are
parameters: `eeprom set panel_stand_mm 1035`, `eeprom set desk_flap_mm 770`.

## debug — tracing what the desk side decides

| Command | Mode | What it does |
|---|---|---|
| `debug` | working | Whether the trace is running, and how many events are waiting to print. |
| `debug start\|stop` | working | Start printing every change that steers a move, timestamped from `debug start`, or stop. Read-only — it changes nothing the firmware does — and off at every boot. |

Each line is `[dbg <seconds>] <what> <detail>`, printed when something
**changes** — a quiet desk prints nothing:

| Line | Means |
|---|---|
| `state A -> B` | the flap state machine: `PASS` (panel in charge), `PLANNING` (a recall seen, waiting for its destination), `STOPPING` (stopping the desk), `MOVING` (the flap job owns the desk) |
| `panel sends …` | the key the panel put on the wire — every button press shows here |
| `recall … : …` | what was decided about a preset press, and **why**: taken over, passed through (and the reason — flap off, hands-off, dev mode, no height), waiting for the board's announcement, or caught late by the approach stop |
| `board hears …` | the key the board actually got — the panel's, or ours in its place |
| `height … mm (going up/down)` | the desk's height, from the board |
| `board announces destination … mm` | where a recall is taking the desk — printed for every announcement, repeats included |
| `flag hands-off / armed / desk locked / intercept = yes/no` | hands-off: the flap ignores the bus while a resumed move finishes; armed: bench builds only (`FLAP_DRIVES_MOTOR 0`) — with a motor, the desk is stopped whenever the flap is not at the end the far side needs; intercept: whether the flap may act at all |
| `job …` | the flap job's phases: takeover (or `manual crossing` for a held key or a tap — no recall afterwards), at the flap height, flap moving to EXPANDED/COLLAPSED, flap there (or move FAILED — the desk stays put), resume (the recall re-sent once), whether it went out, done. `flap fast part over at N%` marks the end of the fast part. With `desk_resume_pct` below 100, `resume` can come before it or before `flap there`. `the desk did NOT set off — … sending it again` means the board dropped the recall (see below) |
| `… events LOST` | the console could not print fast enough; the record has a gap |

**Reading a stand → sit move that stops at the flap.** The sequence should be:
`panel sends SIT recall` → `recall SIT recall: crosses the flap — taken over` →
`job flap takeover` → `state … -> MOVING` → heights
going down → `job at the flap height` → `job flap moving to EXPANDED` →
`job flap there` →
`job resume: re-sending SIT recall once` → `board hears 0x02 SIT recall` →
`job recall went out on the wire` → `board announces destination …` → heights
going down again. The last line before it goes quiet says where it stopped:

| Last thing in the trace | Points at |
|---|---|
| `recall …: PASSED: …` | the press was not taken over; the reason is on the line. Since 2026-10-02 the approach stop catches such a move at the flap height and still finishes it (`caught by the approach stop`) |
| no `at the flap height` | the approach: `[desk]` lines say stalled, timed out, or no height |
| `recall NEVER went out` | the panel stopped polling, so our one-shot frame had nothing to ride on |
| `recall went out`, but no `announces destination` | the board ignored the recall — it was too soon after the stop, or asleep |
| `announces destination`, but no height change | the board accepted it and did not move |

## lim — the flap's travel range

Stored as the MT6835's raw angle at each end, plus two directions: which way
round the flap travels, and which way the motor turns it. No step count.
Until **both** ends are stored the motor only jogs **and the desk refuses every
move** (see [What it needs to move](#what-it-needs-to-move)). `reset` clears
them.

| Command | Mode | What it does |
|---|---|---|
| `lim` | working | The stored range field by field, whether both ends are stored, the directions, and where the shaft is in the range. With nothing stored, it says how to store it. |
| `lim expanded` | dev | Store the shaft's current position as the flap's expanded end. |
| `lim collapsed` | dev | Store it as its collapsed end. Must be in the same session as `lim expanded`, with no `enc zero` in between, so the way round between the ends is known — and the motor must have jogged the flap at least once, so its direction is. The range must fit inside one turn of the magnet's shaft. With a range already stored, `lim expanded`/`lim collapsed` move that end to where the shaft is now. |
| `lim play [<deg>]` | dev | Measure the gearbox backlash by creeping each way until the encoder sees the output move `<deg>` (default 1), and store it as `lim_backlash`. Any time; the calibration does not depend on it. |
| `lim free` | dev | Toggle: ignore the range and the guard until reboot or `lim free` again. For measurements that need whole turns. Nothing then stops the flap hitting its ends. |

## mot — the flap motor

Every move goes through the travel range. Without a stored range only
`mot jog` moves; with one, nothing may leave it, and the encoder hard-stops the
motor `LIMIT_GUARD_DEG` past either end if something does anyway.

| Command | Mode | What it does |
|---|---|---|
| `mot` | dev | Motor state, position, speed, the motion profile, and the driver's status line. The cruise speed is a parameter: `eeprom set mot_speed_sps <n>`. |
| `mot on\|off` | dev | Energise the coils, or release them so the flap turns by hand. |
| `mot accel <sps2>` | dev | Ramp rate, microsteps per second squared. Session only. |
| `mot jog <steps>` | dev | A small signed move, at most one motor revolution. The only move allowed with no range stored, for finding the ends. With a range stored it is range-checked, and from outside the range it may only head back in. |
| `mot go expanded\|collapsed\|<deg>` | dev | Go to the expanded or collapsed end (`expand` / `collapse` work too), or `deg` degrees from expanded — anything else is refused with the usage line: at speed, steered by the encoder, ramping down `lim_approach_deg` short, then crept onto the target to within 0.1° (see [How mot go arrives](#how-mot-go-arrives)). Any key stops it. |
| `mot move <steps>` | dev | Signed relative move in microsteps, refused if it would end outside the range. |
| `mot rev <revs>` | dev | Signed revolutions of the flap shaft, through `GEAR_RATIO`. Same range check. |
| `mot run fwd\|back` | dev | With a range: run to the end of travel that way and settle. Under `lim free`: run until `mot stop`. |
| `mot stop` | dev | Ramp down. |
| `mot halt` | dev | Cut the pulses now, no ramp. Nothing is lost: positions come from the encoder. |
| `mot zero` | dev | Call this position zero (the step counter only; the stored range is in absolute angle and unaffected). |

### How mot go arrives

A `mot go` cannot just run a number of steps and stop. Between motor and flap
there is a gearbox with some play, the flap has weight, and steps can be lost;
a step count is only ever an estimate of where the flap is. **The encoder
decides**, the whole way:

1. **Fast, steered by the encoder.** The motor runs towards the target. On
   every encoder sample (every 2 ms) the firmware works out the distance still
   to go and how far the motor needs to brake from its present speed, and
   ramps it down when the two meet — so it stops `lim_approach_deg` *short* of
   the target.
2. **Creep**: a few microsteps at a time, reading the encoder after each, until
   the flap is within 0.1° (`LIMIT_SETTLE_DEG`) of the target.

The flap therefore always arrives slowly, from the inside of its range. The
gear ratio only sizes the braking distance and the creep increments; if it is
a little off, braking starts a little early or late and the creep absorbs it.

While the fast part runs, the firmware also watches that the flap is
following: no progress for 0.4 s is a **stall** (`[lim] STALL`), and moving
away from the target is a **wrong way** (`[lim] WRONG WAY` — the motor's
direction no longer matches the calibration). Both stop the motor at once.

Example, 171.3° of travel, approach 4°: `mot go collapsed` runs about 167° at
speed and creeps the last 4°.

| lim_approach_deg | Effect |
|---|---|
| larger | safer against a bigger gap, a slower finish |
| 4 (default) | the bench rig's measured worst gap was 3.6° |
| 0 | the whole distance at speed, then corrected afterwards — the flap **can overshoot by the size of the gap first** |

Rule of thumb: bigger than the largest jump the flap makes on its own. Only
`mot go` (and `mot run` with a range) use it; jogs and `mot move` do not.

## tmc — the driver (TMC2209)

Most of these need the UART link (`TMC_UART_ENABLED`). In standalone mode they
explain what the link would give and change nothing.

| Command | Mode | What it does |
|---|---|---|
| `tmc` | dev | How the driver is set up and what it can report: version, wiring, current, microstepping, chopper, registers. Standalone: what the strapping implies. |
| `tmc init` | dev | Re-establish the link after fixing the wiring. |
| `tmc wire` | dev | Loopback test of our own TX and RX pins through the 1 k resistor. No driver needed. |
| `tmc scan` | dev | Ask all four UART addresses which one answers, and use it. |
| `tmc current <run> [hold]` | dev | RMS milliamps per phase; hold defaults to half of run. |
| `tmc micro <n>` | dev | Microsteps, 1..256. Not while moving. |
| `tmc chop stealth\|spread` | dev | StealthChop (quiet) or SpreadCycle (more torque at speed). |
| `tmc reg <hex> [hex]` | dev | Read one register, or write it. |

## enc — the encoder (MT6835)

| Command | Mode | What it does |
|---|---|---|
| `enc` | dev | Is it answering, the raw angle, position since `enc zero`, gearing, and its health counters with what each one means. |
| `enc watch` | dev | Print the angle while the shaft is turned by hand, only when it moves. `z` zeroes, any other key stops. |
| `enc zero` | dev | Call this shaft position zero. The raw angle, which the range is stored in, is unaffected. |
| `enc dir [0\|1]` | dev | Which way the angle counts (a sensor register, volatile). |
| `enc gear [<n>]` | dev | The reducer between motor and magnet, N:1. Session only; `GEAR_RATIO` at reboot. |
| `enc reg <hex> [hex]` | dev | Read or write one sensor register. |

## What it needs to move

Two things, checked at every panel frame and before every motor move:

1. **The MT6835 answers.** Live hardware, not a stored value: the encoder task
   must have had a valid frame from it.
2. **The flap is calibrated** — these stored parameters are set:

   | Parameter | What it is |
   |---|---|
   | `lim_flags` | both bits set: both ends are stored |
   | `lim_expanded_raw` | the flap shaft's angle at its expanded end |
   | `lim_collapsed_raw` | its angle at its collapsed end |
   | `lim_enc_dir` | which way round the flap travels from expanded to collapsed |
   | `lim_mot_dir` | which way the motor turns to collapse it |

   They are measured together — by `calibrate`, or `lim expanded` then `lim collapsed` in dev
   mode — and only make sense as a set. They are read-only through `eeprom`, and **`reset` clears exactly
   these five** — nothing else.

Every other parameter has a working value from the start and never blocks a
move: the presets are learned, the coast and flap height come from
`board_config.h`, backlash defaults to none and approach to
`LIMIT_APPROACH_DEG`.

**If either check fails:**

| | What happens |
|---|---|
| desk | **every move is refused**: the panel's UP, DOWN and preset recalls are replaced with idle before they reach the board, and `go` says why. **The board's LED blinks red three times** for each refused press, so whoever is at the panel can see it was heard and refused on purpose. Saving a preset and the panel's wake code still pass; a move already being stopped finishes stopping. `status` shows `DESK LOCKED`, the reason, and how many moves were refused. |
| flap motor | only `mot jog` moves it, at most one motor turn per command, so the ends can be found. Everything else is refused. |

The reason for locking the desk: the flap sits in the desk's path. Until the
firmware can see the flap and knows where its ends are, it cannot tell whether
moving the desk is safe. Decided 2026-10-02 while the flap is being fitted; see
[operation.md](operation.md#working-mode-and-dev-mode).

## Calibrating

`calibrate` is how a board gets its calibration: on a fresh board, after `reset`, or
whenever the flap's ends have moved. It needs no `dev start` — a board with a
locked desk must be fixable by whoever is standing at it — and the boot banner
suggests it whenever the flap is not calibrated.

```text
> calibrate
flap calibration cleared — ...           # step 0: the five parameters above
CALIBRATE 1/2 — move the flap to its EXPANDED position with the motor:
calibrate expanded> mot jog -400                   # signed microsteps, one motor turn max
calibrate expanded>                                # Enter repeats the last jog
calibrate expanded> mot jog 50                     # fine-tune
calibrate expanded> done                           # lim_expanded_raw stored
CALIBRATE 2/2 — move the flap to its COLLAPSED position ...
calibrate collapsed> mot jog 400
calibrate collapsed>                                # ... Enter, Enter, ...
calibrate collapsed> done                           # lim_collapsed_raw stored, the rest worked out
CALIBRATION COMPLETE — the desk is unlocked.
```

- **Only `lim_expanded_raw` and `lim_collapsed_raw` are positions.** The other
  three are worked out on the way: `lim_flags` (both stored), `lim_enc_dir`
  (which way round the flap went between the two marks) and `lim_mot_dir`
  (which way the motor turned it, learned by watching the encoder during the
  jogs). Nothing is counted, so nothing can be miscounted.
- **The flap may be turned by hand** (`mot off` releases the coils), as long as
  the motor jogs it at least once along the way, by more than half a degree —
  that is how its direction is learned. Otherwise `calibrate` says so.
- **Jogs are capped** at one motor revolution each, because there is no range
  yet to check a bigger move against. With the gearbox that is a small turn of
  the flap, so Enter-to-repeat does the travelling.
- While `calibrate` runs, `mot` and `enc` work without `dev start`; everything else
  keeps its usual mode. `status` and `?` work as normal.
- If the two marks do not make a usable range — the same place, or more than
  one turn of the shaft apart — `calibrate` says so and starts again from expanded.
- `abort` leaves it with the calibration cleared and the desk locked.
- Backlash: `lim play` measures it, before or after calibrating.

The record is written to flash a couple of seconds after `done`, once the motor
is still (`[settings] saved: ... limits stored`). `eeprom` shows what was stored.

## Stored parameters

What `eeprom` lists: one CRC-checked record in the last flash sector, owned by
[`../src/settings.c`](../src/settings.c). Each name is `<section>_<field>`, and
the section is the console group it belongs to (`mot_*` is the flap motor).
**Needed** marks the calibration the desk and the motor cannot move without —
the five `reset` clears. [Parameters explained](#parameters-explained) below says
what each one means in practice.

| Parameter | Unit | Meaning | `eeprom set` | Needed |
|---|---|---|---|---|
| `version` | — | the record's layout; an older one is still read and upgraded | read-only | |
| `panel_stand_mm` | mm | the stand preset's height; 0 = not known yet | working | |
| `panel_sit_mm` | mm | the sit preset's height; 0 = not known yet | working | |
| `desk_coast_up_mm` | mm | how far the desk keeps moving up after being told to stop | working | |
| `desk_coast_down_mm` | mm | the same, going down | working | |
| `desk_flap_mm` | mm | the height the desk is stopped at so the flap can move | working | |
| `desk_flap_on` | 0\|1 | whether the desk is stopped there and the flap moved. With 0 the flap is never moved, and the crossing guard refuses any move up past the flap height while the flap is not collapsed | working | |
| `desk_resume_pct` | % | when the desk moves on after the flap: once the flap has covered this share of its move, by the encoder. 100 (default) = once it has settled on its end. On this desk below 100 gains at most ~0.5 s ([why](#when-the-desk-moves-on-desk_resume_pct)) | dev | |
| `lim_flags` | bits | which ends are stored: 1 = expanded, 2 = collapsed, 3 = both | read-only: `lim expanded`, `lim collapsed` | **yes** — `reset` clears it |
| `lim_expanded_raw` | raw | the encoder's reading with the flap at its expanded end | read-only: `lim expanded` | **yes** — `reset` clears it |
| `lim_collapsed_raw` | raw | the encoder's reading with the flap at its collapsed end | read-only: `lim collapsed` | **yes** — `reset` clears it |
| `lim_enc_dir` | +1\|-1 | which way round the flap travels from expanded to collapsed: +1 the raw angle counts up | read-only: `calibrate` | **yes** — `reset` clears it |
| `lim_mot_dir` | +1\|-1 | which way the motor turns to collapse the flap: +1 forward | read-only: `calibrate`, learned from the motor | **yes** — `reset` clears it |
| `lim_backlash` | microsteps | the gearbox's play, added to open-loop moves that change direction | dev (`lim play` measures it) | |
| `lim_approach_deg` | deg | how far before its target a `mot go` slows to a creep | dev | |
| `mot_speed_sps` | steps/s | the flap motor's cruise speed, 100..15000 | dev | |
| `mot_early_start` | 0\|1 | when the flap starts: 0 = once the desk has stopped at the flap height, 1 = the moment the desk is told to stop | dev | |

Not stored, from `board_config.h` at every boot: proxying (always on), the
ceiling switch, `mot accel`, `enc gear`, `enc dir`, and the mode.

The record carries a layout `version`. New fields are only ever added at the
end, so a record written by older firmware is still read: its values are kept,
the new fields take their defaults, and it is rewritten in the new layout — a
firmware update never costs the flap calibration.

## Parameters explained

### Desk heights: `desk_flap_mm`, `panel_*_mm`, `desk_coast_*_mm`

All in **millimetres of desk height**, the same number the panel shows ×10
(74.3 on the panel = 743).

- **`desk_flap_mm`** — the height the flap needs the desk to be at before it can
  move. Any move that would carry the desk across it — a preset, a held key or
  single taps — is stopped there first and the flap is moved.
  `desk_flap_on 0` turns that off; the flap is then never moved, and the desk
  is refused any move **up** past the flap height — or further up, if it is
  already above it — while the flap is not collapsed (see the crossing guard in
  [operation.md](operation.md#how-a-preset-is-handled)).
- **`panel_stand_mm`, `panel_sit_mm`** — where the panel's two preset buttons
  take the desk. Learned by watching: when a preset is pressed, the board
  announces its destination a second before it moves; that is compared with
  the stored height and written **only if it differs**. Known in advance, a
  preset that would cross the flap height is caught before the board even hears
  it. 0 = not learned yet. These two are the only parameters stored without a
  command — [operation.md](operation.md#how-a-preset-is-handled) has the rules.
- **`desk_coast_up_mm`, `desk_coast_down_mm`** — **coast** is how far the desk
  keeps moving after it has been told to stop: the board ramps the motors down
  rather than stopping dead. To stop *at* a height, the stop has to go out that
  much *early*:

  ```text
  going up to the flap at 770, coast up 18:

     752 ─── stop sent here (770 − 18)
      │      the desk coasts on ...
     770 ─── ... and settles about here
  ```

  Used by the flap stop and by `go`. When the desk is already closer than a
  coast to where it has to stop, a release would overshoot, so it steps there
  instead with 10 mm taps (a tap is a fixed step and cannot coast). It does not
  need to be exact:
  landing within 10 mm (`DESK_NEAR_MM`) counts as there. If stops keep landing
  short or long by the same amount, change it by that amount; `go` prints where
  it actually stopped.

### The flap's calibration: `lim_*`

Measured by `calibrate` (or `lim expanded` / `lim collapsed`). The flap shaft carries a magnet,
and the MT6835 reads its angle as a number from 0 to 2 097 151 for one full
turn — 5 825 counts per degree. That number is absolute: it is the same after
a power cut, which is why the ends are stored as angles.

An example — this flap's calibration of 2026-10-02 (it has been redone since,
and is now ~172.4° of travel):

| Parameter | Value | Read as |
|---|---|---|
| `lim_expanded_raw` | 1 382 270 | the shaft at 237.28° when the flap is at its expanded end |
| `lim_collapsed_raw` | 336 164 | at 57.71° when it is at its collapsed end |
| `lim_enc_dir` | −1 | from expanded to collapsed the reading goes **down**: 237.28° → 57.71° is 179.6° that way round (the other way round would be 180.4°) |
| `lim_mot_dir` | −1 | the motor turns **backward** to collapse the flap |
| `lim_flags` | 3 | both ends stored |

- **The two angles are the only positions.** Everything else is a direction.
  Two angles on a circle make two arcs; `lim_enc_dir` says which one is the
  flap's travel, which matters when the range is near half a turn, as here.
- **No step count is stored.** Moves are steered by the encoder (see
  [How mot go arrives](#how-mot-go-arrives)), so a wrong count — lost steps
  while calibrating, a changed microstepping, a gear ratio slightly off —
  cannot make the flap fall short any more. Until 2026-10-03 the span was also
  stored in motor steps, and a miscounted one made every move creep the last
  quarter of its travel.
- **`lim_mot_dir` corrects itself**: every motor move is watched, and if the
  motor turns out to go the other way (the motor's wires swapped, say), the
  stored direction is changed to match.
- **The range must fit within one turn of the shaft**, since the encoder cannot
  tell one turn from the next.

### Gearbox play: `lim_backlash`

Gears have a little slack between their teeth. When the motor **changes
direction**, it first turns a few microsteps through that slack before the flap
moves at all.

```text
motor:  ──────►  stop  ◄── 0 … backlash … ──◄◄◄ flap starts moving
                        (motor turns, flap does not)
```

`lim_backlash` is that slack in microsteps. Every **open-loop** move that
reverses direction (`mot jog`, `mot move`, `mot rev`) is made that much longer,
so the *flap* travels the distance asked for. `mot go` and the flap's own moves
do not need it: they stop on the encoder. 0 (the default) compensates nothing.

`lim play` measures it: it creeps one way, then the other, a few microsteps at
a time with the coils released between steps, and notes when the encoder sees
the flap start to move. It can be measured at any time.

### Arriving without overshooting: `lim_approach_deg`

How far before its target a `mot go` stops running at speed and starts to
creep. See [How mot go arrives](#how-mot-go-arrives). In short: the flap's own
weight can carry it through the gearbox play past where the motor stopped, so
the last `lim_approach_deg` degrees are crept a few microsteps at a time, the
encoder read after each, until it is within 0.1°. Default 4°; larger is safer
and slower; 0 = no creep, and the flap may overshoot first.

### Motor speed: `mot_speed_sps`

How fast the flap motor turns once it has accelerated, in microsteps per
second. With 1 600 microsteps per motor turn and the 17.23:1 gearbox, the
default 5 000 is about 3.1 motor turns a second = **65° of flap per second**, so
a travel of ~172° (this flap, 2026-10-03) takes about 2.7 s plus the ramp and
the creep — measured: the fast part done in ~2.6 s. The motor was
measured stable to 15 000 without load; keep well under that with the flap on
it. Acceleration (`mot accel`) is not stored.

**A stall means a long creep.** If the motor cannot turn the flap during the
fast part it skips steps: the flap barely moves, and the creep — a few
microsteps at a time — then covers the whole travel, 20–30 s instead of 3. The
flap still arrives, and the firmware warns:

```text
[flap] STALL: the motor skipped most of the fast part (12896 steps crept).
```

Seen on 2026-10-02, and the cause was **the driver's supply**: the TMC2209 was
powered from the controller board's power output port, and the board **cuts
that output while the desk is moving** (confirmed with a meter). The motor lost
power mid-move, dropped out of step and could not recover at speed. Powered
from a separate supply it runs at the default 5000 without trouble —
[wiring.md](../../docs/wiring.md#power). If a stall shows up with a good supply, lower the speed
(`eeprom set mot_speed_sps 2500`) or soften the ramp (`mot accel 10000`).

### When the flap starts: `mot_early_start`

- **0 (default)** — the flap starts once the desk has stopped at the flap
  height (within 10 mm of it with the height unchanged for 0.4 s — the board ends a move up with a slow crawl — or unchanged for 1.2 s further off).
- **1** — the flap starts the moment the desk is told to stop: at the release
  point of the approach, or when the stop key goes out. The desk's coast and
  the flap's travel overlap, which saves about a second per crossing.
  Measured 2026-10-03 at `mot_speed_sps` 5000: by the time the desk has
  stopped at the flap height, the flap is already **93–99%** of the way.

Either way (and unless `desk_resume_pct` is below 100) the recall is only re-sent once the desk is still **and** the
encoder confirms the flap is at its end. With 1, the flap motor runs while the
desk's motors are still running, so the driver needs a supply that stays on
while the desk moves — the controller board's power output does not (below).

### When the desk moves on: `desk_resume_pct`

The recall that sends the desk on to its preset is re-sent once the flap has
covered **this share of its move**, measured by the encoder — from where the
flap started to the end it is going to.

- **100 (default)** — once the flap has **settled on its end**, confirmed by
  the encoder to within 0.1°. If the flap does not get there, the desk stays at
  the flap height.
- **below 100** — as soon as the flap is that far along. The desk's ~1 s start-up
  then overlaps the rest of the flap's travel. 80, say, sends the desk on with
  the last fifth of the flap's move still to go.

The share is checked throughout the fast part and once more at its end. The
recall is only queued at that moment — the flap carries on at once, and the bus
sends the recall on the panel's next poll.

**The recall waits for a desk that has really stopped**: its height unchanged
for 1.2 s. Going up, the board ends a move with a slow crawl, and a recall that
arrives during it is announced and then **dropped** — the desk stays at the
flap height (seen 2026-10-03). So the share may be reached first and the
recall still wait a moment. And if, 4 s after the recall, the desk has not
moved 5 mm towards its destination, the recall is sent once more
(`[flap] the desk did not set off — the recall was dropped. Sending it again.`). The
fast part stops `lim_approach_deg` short of the end (about 98% of a full
travel), so a value above that is reached only by the creep — and then behaves
like 100.

The price of anything below 100: **if the flap then fails, the desk cannot be
held back** — it has already resumed. The console says `FLAP MOVE FAILED — the
desk had ALREADY resumed` and the LED blinks red. And the flap finishes while
the desk's motors run, so the driver needs a supply that stays on during a
move.

**On this desk it makes almost no difference — leave it at 100.** The recall
can never go before the desk has been still for 1.2 s (above), and with
`mot_early_start 1` at the default 5000 steps/s the flap is already **93–99%**
of the way by then (measured 2026-10-03, both directions). So any value below
~93 triggers at that same moment, no earlier, and the most it saves is the end
of the creep — 0.3–0.5 s, going down only. It would only matter with a much
slower flap, or with `mot_early_start 0`. Its cost is real either way: a flap
that fails after an early resume cannot hold the desk back.

Replaced `desk_early_resume` (0|1: resume once the fast part was over) on
2026-10-03; an older record gets 100.

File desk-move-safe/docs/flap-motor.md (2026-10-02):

# The flap motor

A NEMA 17 through a reduction gearbox, on a TMC2209 in the driver's standalone
**STEP / DIR / EN** mode — the same way the bench rig at
`../../../test/nema_MT6835` runs it, so the port is a copy.

## Wiring

```
   TMC2209 carrier          RP2350
   ---------------          ------------------
   VDD                      3V3          not 5V — GPIOs are not 5 V tolerant
   GND                      ground node  common with the motor supply
   DIR                      GP6
   STEP                     GP7
   EN                       GP8          active low
   MS1, MS2                 strapped     microstep select, see below
   VREF                     trimmer      THE CURRENT LIMIT. Set it first.
   PDN_UART                 —            unconnected
   VM, GND                  12-24 V PSU
   1A 1B 2A 2B              motor coils  one pair per coil, ohm them out first
```

GP6–GP8 are three consecutive pads wrapping the bottom-right corner — GP7 ends
the right edge, GP8 begins the bottom — so the driver harness is one connector.
GP9 to GP11 continue the run for the optional UART pair and DIAG.

GP0, GP1, GP4 and GP5 belong to the desk bus; GP26–GP29 (SPI1) are reserved for
the MT6835, at the far end of the board so the sensor cable runs as far from the
driver as it can. On the RP2350A Supermini GP16 drives the onboard
WS2812 and GP17–GP25 are back-side inner pads, so the bench rig's SPI0 group at
GP16–GP19 does not exist here at all — the full map is in
[../../docs/wiring.md](../../docs/wiring.md).

## Two things to get right before the first run

**Microstepping is strapping, and the firmware has to be told.** MS1/MS2 both
low or floating is 1/8 on the TMC2209 — not the A4988 table, and there is no
full-step mode.

| MS2 | MS1 | microsteps |
|---|---|---|
| 0 | 0 | 1/8 ← power-on default |
| 0 | 1 | 1/2 |
| 1 | 0 | 1/4 |
| 1 | 1 | 1/16 |

`TMC_MICROSTEPS` must match. Nothing detects a mismatch: every revolution
figure, and later every travel limit, is off by that ratio and silent about it.

**VREF is the current limit.** Software cannot see it or change it in this mode.
On a 0.11 Ω carrier, `I_rms ≈ 0.71 × VREF`. Check the sense resistor while you
are there — 0.10 Ω, 0.11 Ω and 0.15 Ω all ship on boards sold under the same
description, and it scales everything.

## Bring-up

Every command below is **development only** — the board boots into working mode
and refuses them until you say so:

```text
dev start               unlock the motor commands; gone at the next reboot
```

Working mode is not a reduced console, it is the console for a board under a
desk: `status`, `stop` and all the desk configuration stay available. What is
behind the gate is everything that drives something directly, because none of it
has any business happening because of a mistyped line on a desk in use. See
[operation.md](operation.md).

```text
mot                     what the motor is doing and how it is set
mot on                  coils live
mot rev 0.25            a quarter turn of the flap shaft
mot accel 2000          a deliberate ramp you can hear wind up
mot accel 10000000      no ramp at all — usually a stall and a whine
```

That last pair is the whole argument for the ramp engine: the driver turns one
STEP edge into one microstep and has no idea any of this is happening.

The cruise speed is a stored parameter rather than a `mot` command:
`eeprom set mot_speed_sps 2000` slows it if the motor is skipping, and it stays
that way across resets.

If nothing moves: EN is active low, so GP8 has to go **low** to energise the
coils, which `mot on` does. Then VM. Then the coil pairs — a NEMA 17 wired
A1/B1/A2/B2 instead of A1/A2/B1/B2 buzzes and does not turn.

## Verified register dump

Read off the replacement driver with `usb-uart-tools/tmc_test.py` on 2026-09-27,
with VM live and nothing having configured the chip — so this is what a healthy,
untouched TMC2209 in standalone mode actually reads. Useful as a reference when
something looks wrong.

| register | value | what it says |
|---|---|---|
| `IOIN` | `0x21000041` | VERSION **0x21 = TMC2209**. ENN=1 (disabled), MS1=0, MS2=0, DIAG=0 |
| `GCONF` | `0x00000101` | `I_scale_analog`=1 → **current from VREF**; `mstep_reg_select`=0 → **microsteps from MS1/MS2**; `en_spreadCycle`=0 → **StealthChop** |
| `CHOPCONF` | `0x15010053` | TOFF=3, **MRES=5 → 1/8 microstepping**, `intpol`=1, TBL=2, HSTRT=5, HEND=0 |
| `DRV_STATUS` | `0xC01F0000` | standstill, StealthChop active, **no faults at all** — no over-temperature, no short, no open load. CS_ACTUAL 31/31 |
| `IFCNT` | `0x00000000` | no register write has ever been accepted, as expected |
| `GSTAT` | `0x00000001` | `reset`=1 — it has been reset since GSTAT was last cleared. Not a fault |

Two things worth taking from that:

- **MRES=5 confirms 1/8**, read back from the chip rather than assumed from the
  strapping. `TMC_MICROSTEPS 8` in board_config.h is correct for this board.
- **StealthChop is what MS/SPREAD strapping selects by default**, and it has
  noticeably less torque at speed than SpreadCycle. If the flap ever needs to
  move faster than it comfortably will, that is the first lever — tie SPREAD
  high, or turn the UART on and write one register.

And one thing the dump settles: **the UART link on this board works.** The
wiring, the 1 kΩ and the carrier's jumper were all correct; the silence earlier
was the driver that later turned out to be dead. So the switch below is a genuine
one-line decision, not a project.

## A dying driver looks like a slow motor

Worth knowing before you spend an evening on torque, current and resonance: a
**partly failed TMC2209 presents as a low speed ceiling, not as a dead motor.**
One phase driver degrades, the motor still turns, still holds, still sounds
normal at low speed — and then stalls somewhere well below where it used to run.

The give-away is that a torque ceiling should be *monotonic*. If a speed fails
that a lower speed and a higher speed both survive, or if a speed that used to
work no longer does with nothing else changed, suspect the carrier before the
tuning. Swapping in another driver takes a minute and answers it outright.

A dead driver is also silent on UART, which is worth remembering because it
looks exactly like a wiring fault: `usb-uart-tools/tmc_test.py` reads one
register from a laptop and settles it in seconds, with no firmware involved.

Two of these in one project is not bad luck, it is a cause. The usual ones, in
order: **unplugging the motor while VM is live** (the inductive kick has nowhere
to go), **no bulk capacitor at the driver** so every acceleration is a supply
transient, and a supply whose turn-on overshoots. The four rules above exist for
exactly this.

## The MT6835

Four wires to SPI1, at the far end of the board from the driver:

```
   MT6835 breakout          RP2350
   ---------------          ------------------
   VCC                      3V3          3.3 V, not 5 V
   GND                      ground node
   CLK                      GP26         SPI1 SCK
   MOSI                     GP27         SPI1 TX
   MISO                     GP28         SPI1 RX
   CS                       GP29         plain GPIO, driven by hand
```

The bottom (SPI) header is all that is used. The top header — A/B/Z, U/V/W, PWM
— and HVPP stay empty: the angle arrives over SPI, so those are redundant here.

The magnet must be **diametrically** magnetised, 0.5–3 mm above the package and
centred on the shaft axis. That mounting is most of the work, and the sensor
tells you when you have it wrong — see WEAK FIELD below.

### Checking it (dev mode)

```text
dev start
enc                 is it there, where is the shaft, and every health counter
enc watch           stream the angle while you turn the shaft by hand
enc zero            call this position zero
enc dir [0|1]       flip which way the angle counts
```

`enc watch` prints a line five times a second until you press a key. **Standing
still is informative too**: the jitter you see is the noise floor, and more than
a few hundredths of a degree means the magnet is too far away or off axis.

Two things that version got wrong the first time, both worth knowing if you
write anything similar:

- **It drains the input buffer before watching.** A terminal sending CRLF gives
  two characters; the console dispatches on the `\r` and leaves the `\n` queued,
  so an "any key stops" test reads it immediately and the command returns having
  printed nothing. The twin `>` prompts after every command are the same `\n`
  showing up as an empty line.
- **It prints whole lines, not `\r` in place.** Rewriting one line looks neater
  in a terminal that honours carriage return and is unreadable in one that does
  not, and the VS Code serial monitor is the second kind.

A missing sensor is a definite answer rather than a maybe. Every byte reads as
`0xFF` on a floating, pulled-up MISO, and the CRC of three `0xFF` bytes is `0x0F`
— so "no sensor" fails the CRC deterministically instead of being read as a
plausible angle.

The three counters in `enc` mean different things and have different fixes:

| counter | what it means |
|---|---|
| **CRC failures** | wiring — a lead, a missing ground, or a clock too fast for flying leads. Not magnets. |
| **weak field** | the magnet: too far from the package, too small, or not diametrically magnetised. Reported as a fraction of all samples, with the age of the most recent one — because a count that stopped climbing minutes ago was you positioning the magnet, not a fault. |
| **jumps** | a warning line, not an error: a sample saw more than a quarter turn. The unwrap stays correct up to *half* a turn, so a handful alongside a similar `late` count is one delayed sample covering a longer interval. Only a count climbing during normal movement means the sampling cannot keep up. |

If the count runs backwards relative to the motor, `enc dir 1` fixes it — on
this part direction is a register bit, not a strapped pin. It is volatile until
burnt to the sensor's EEPROM.

### What depends on it

Everything that moves. Without a valid frame from the MT6835 the desk is
locked — every panel move refused — and the flap motor only jogs. See
[commands.md](commands.md#what-it-needs-to-move).

## What this mode cannot tell you

Over-temperature, a shorted phase and an open coil all look exactly like a
working motor. That is what the UART would have reported for nothing.

A stall used to be on that list. It is not any more — open-loop STEP/DIR still
emits an identical pulse train whether the motor followed it or not, but the
shaft is measured now, so the difference is a number in degrees.

## The UART option, and why it is off

The driver can also run on a serial link over PDN_UART. It is built and it
works — `TMC_UART_ENABLED` in `board_config.h` turns it on, and
`TMC_USE_DIR_PIN` / `TMC_USE_EN_PIN` then move DIR and EN into registers. GP9
and GP10 are reserved for it: TX through a 1 kΩ, RX on the same node, joined at
this board so a single wire leaves for the driver. Both configurations are kept
compiling, and an incoherent one — no UART *and* no DIR/EN pins — is a compile
error rather than a motor that will not move.

**What it buys:** current and microstepping as numbers instead of a trimmer and
jumpers; over-temperature, short and open-coil reporting; StallGuard; and three
wires down to two.

**What it costs**, which is why one wire did not pay for it:

1. **VM must be live before the chip answers at all.** Not a brown-out, not a
   marginal case — with the motor supply off the UART is silent, permanently,
   and the symptom is identical to a broken wire.
2. **A solder jumper on the carrier ships unbridged.** Watterott
   SilentStepSticks need ["the jumper on the driver … bridged from the middle to
   the respective
   position"](https://learn.watterott.com/silentstepstick/pinconfig/tmc2209/);
   other boards break out a pad marked `UART` or `USART` that is connected to
   nothing. Until that blob exists, perfect wiring and perfect firmware produce
   perfect silence.
3. **The 1 kΩ is not optional** — both ends drive the one pad, and without it no
   reply survives its CRC.
4. **MS1/MS2 become the UART address**, the same pins that used to select
   microstepping. A driver on the wrong address is silent exactly like a driver
   that is not there.

Three pins that either work or visibly do not, against two pins plus four new
ways to be silently wrong. Turning it on is a one-line change whenever that
trade looks different — and the diagnostics survive: `tmc` names which of five
failures happened, `tmc wire` loops back on our own two pins with no driver
attached, and `tmc scan` asks all four addresses.

## Where this is going

1. **Rotation** — done. The AVR446 ramp out of an alarm ISR, `mot` and `tmc`.
2. **MT6835** — done. The 21-bit encoder on SPI1, `enc` and `enc watch`, and
   the boot self-check now asks it a real question.
3. **Travel limits** — done. `limits.c` from the rig: both ends stored in flash,
   backlash, and the creep onto a target under the encoder, calibrated with
   `calibrate`. Its values go in `settings()->lim` and it marks the settings dirty
   like everything else — `nvs` keeps exactly one record and `settings.c` is
   the only thing that may write it.
4. **The desk** — done. The flap move (`flap_start()` / `flap_finish()`) collapses the flap when the desk goes up
   past the flap height and expands it when it goes down, once the desk
   has stopped there; a flap that does not get there leaves the desk where it is. See
   [operation.md](operation.md#the-flap-move).

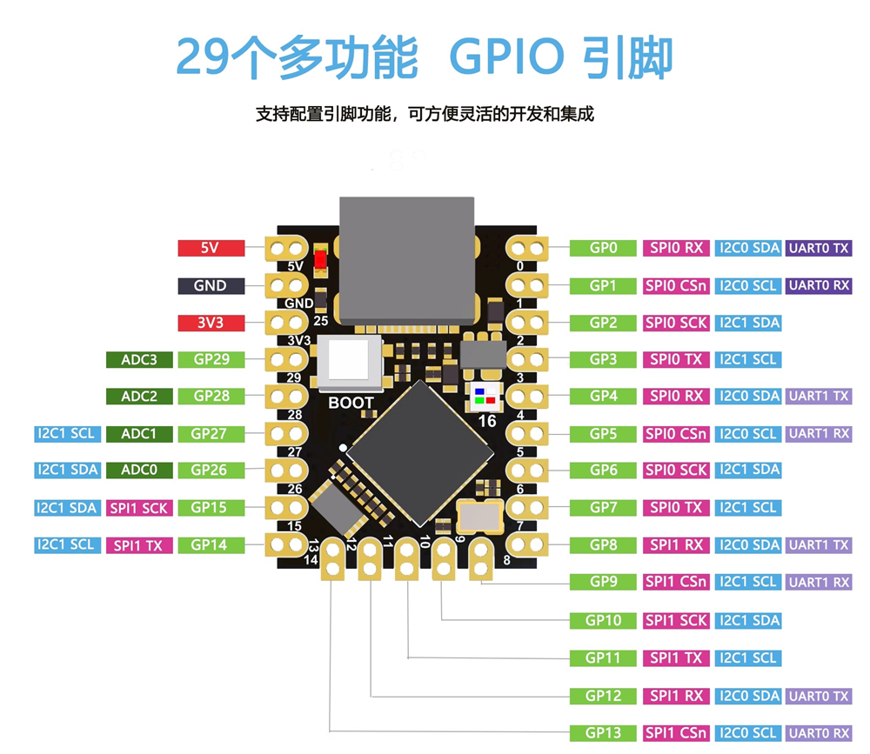
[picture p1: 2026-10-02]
docs/rp2350/board_pinout_top.png

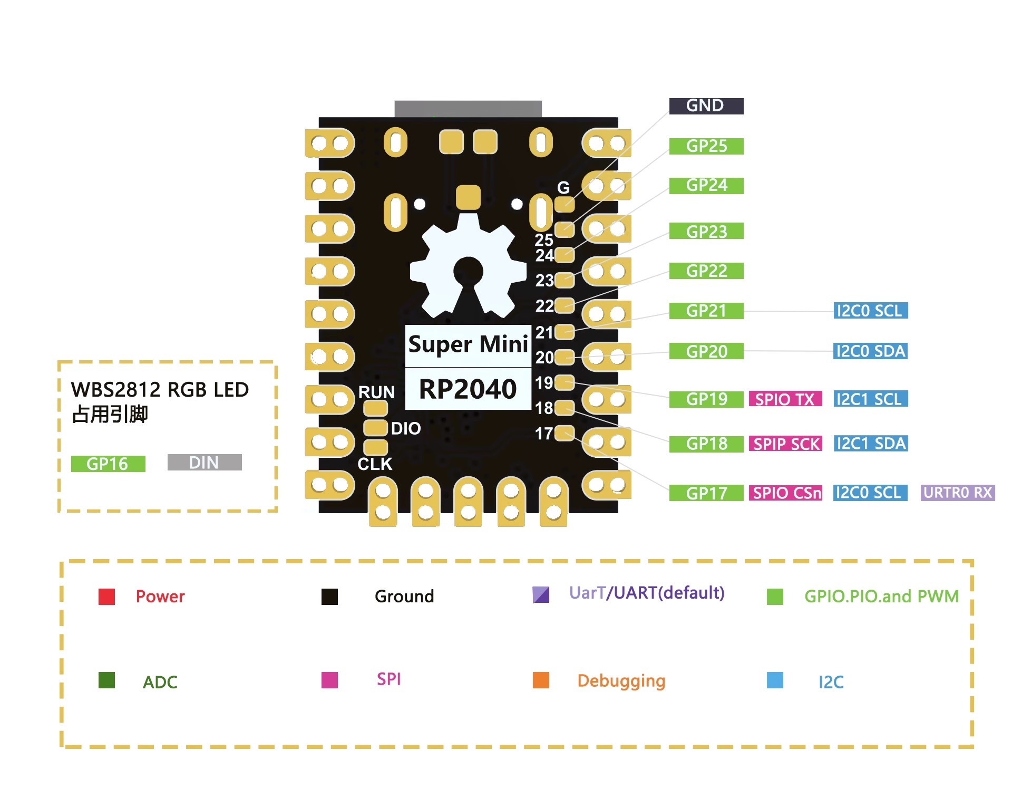
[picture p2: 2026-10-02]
docs/rp2350/board_pinout_bot.png

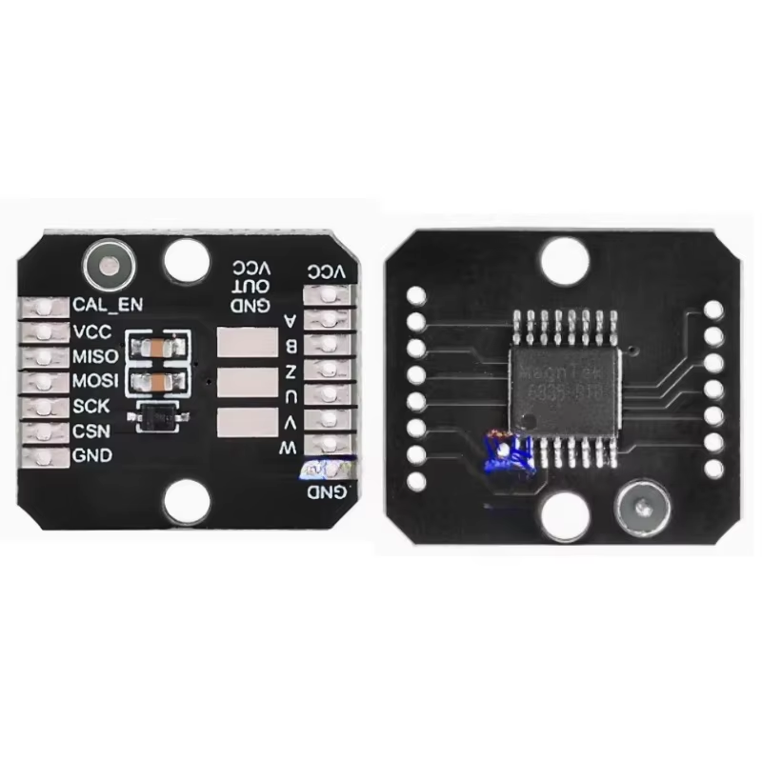
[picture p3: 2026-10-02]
docs/MT6835.png

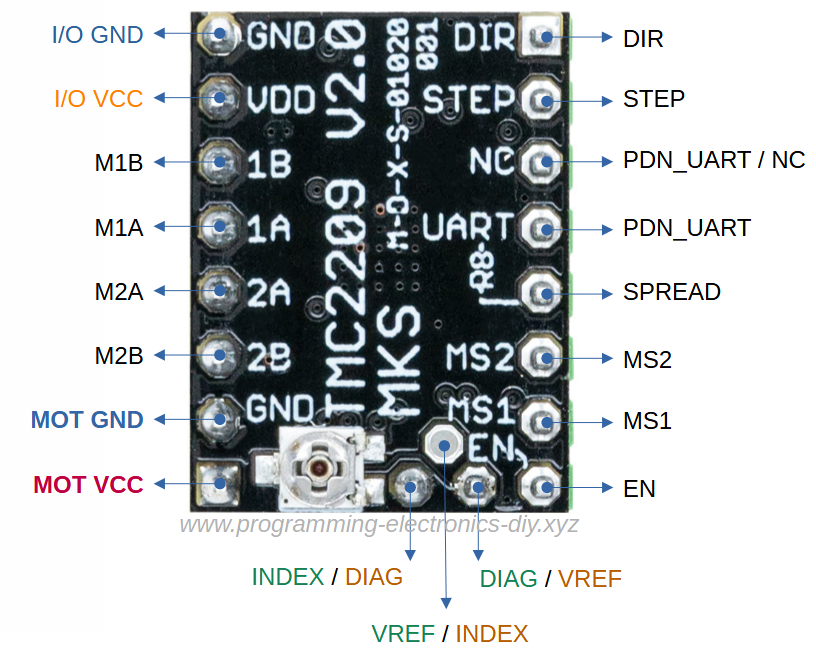
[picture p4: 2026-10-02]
docs/tmc2209/tmc2209_top2.png

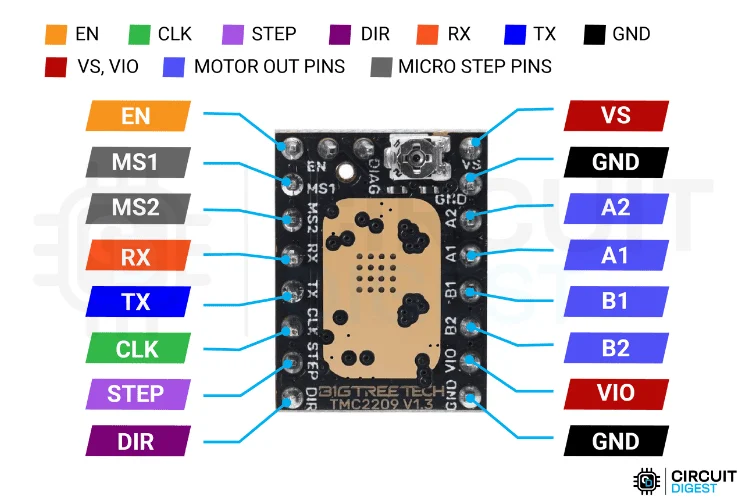
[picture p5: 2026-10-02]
docs/tmc2209/tmc2209_top.png

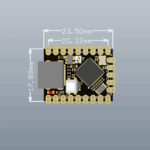
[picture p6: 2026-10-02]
docs/rp2350/board_size.png

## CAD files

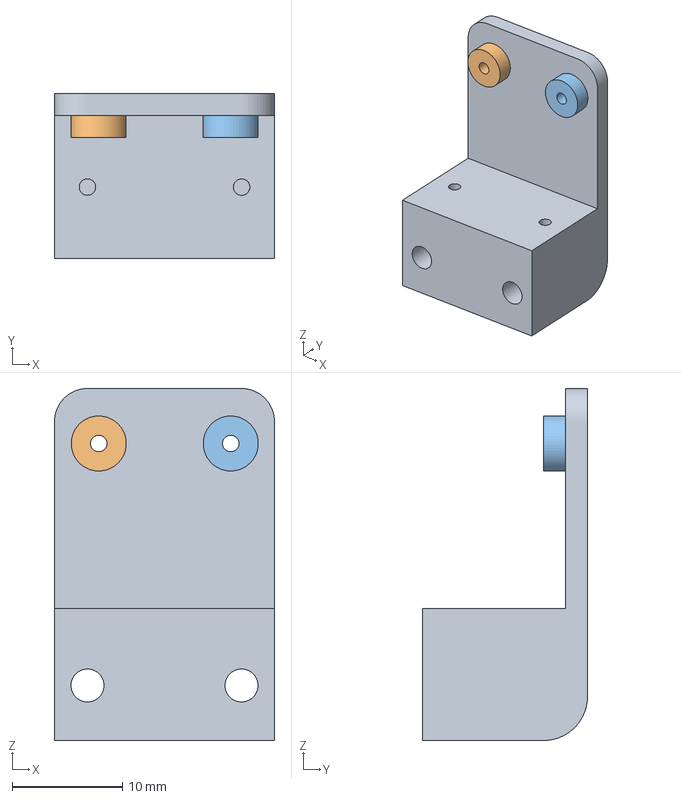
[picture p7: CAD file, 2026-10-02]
3d-models/fusion/encoder-holder.3mf
20.0 x 15.0 x 32.0 mm

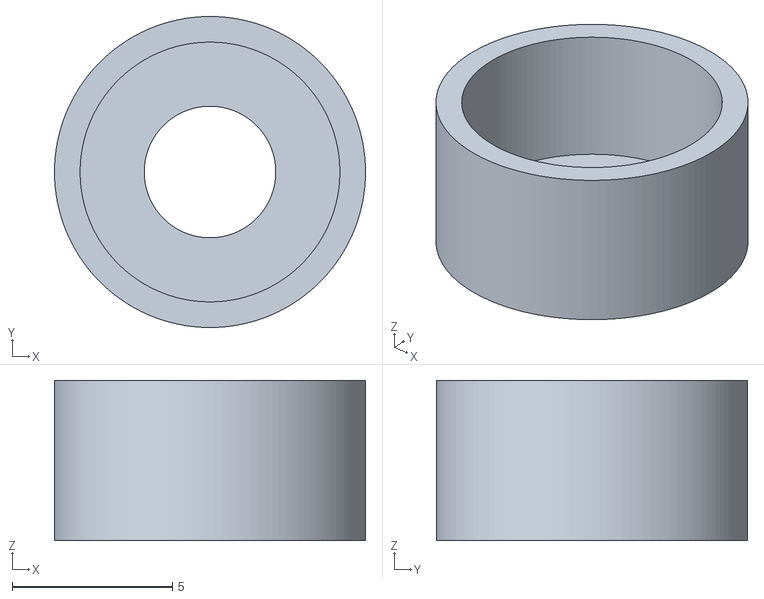
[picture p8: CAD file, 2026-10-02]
3d-models/magnet-centralize.stl
9.70 x 9.70 x 5.00

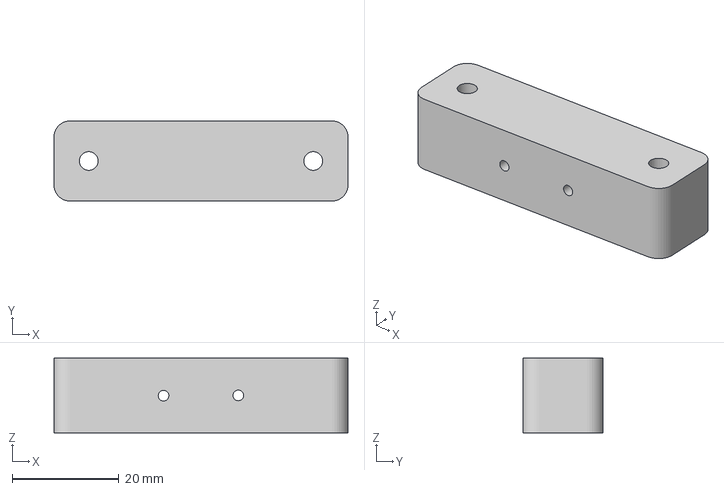
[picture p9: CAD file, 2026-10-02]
3d-models/fusion/kp8-stand.3mf
55.0 x 15.0 x 14.0 mm

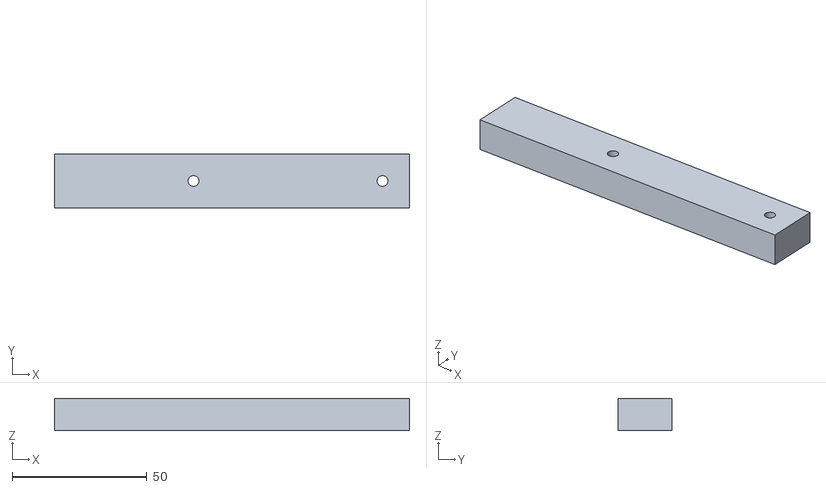
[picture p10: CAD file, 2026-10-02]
3d-models/panel-holder.stl
131.5 x 20.0 x 12.0

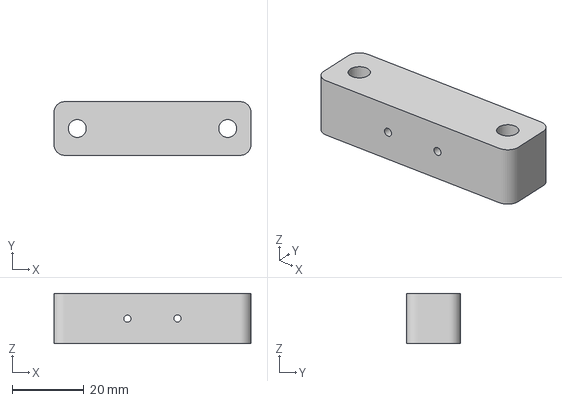
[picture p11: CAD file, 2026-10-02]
3d-models/fusion/kp-with-stand.3mf
55.0 x 15.0 x 14.0 mm

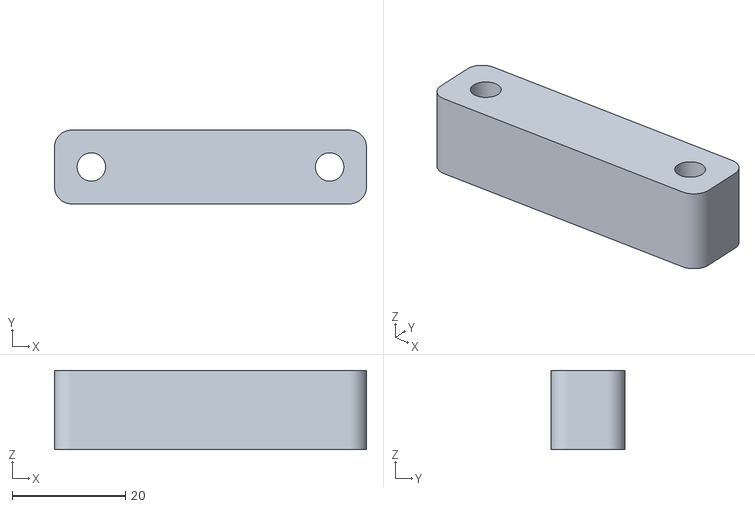
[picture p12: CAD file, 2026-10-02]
3d-models/roll-stand.stl
55.0 x 13.0 x 14.0

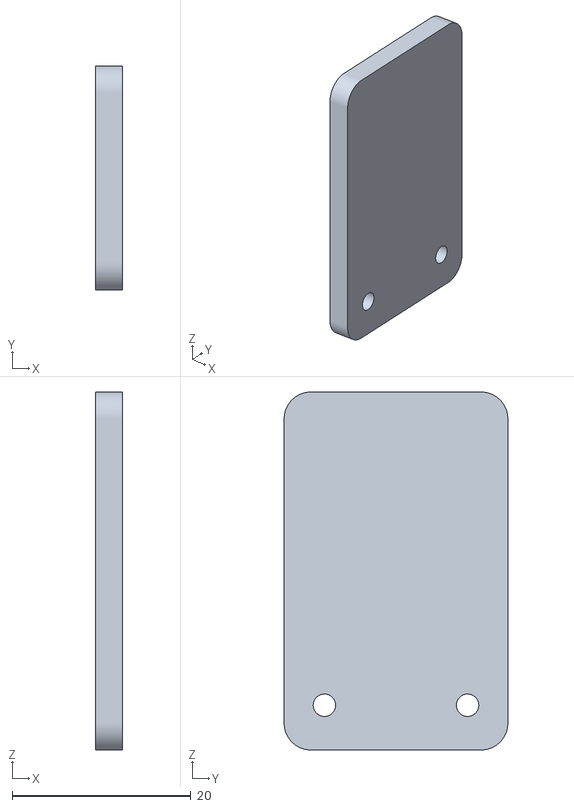
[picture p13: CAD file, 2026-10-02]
3d-models/angle-sensor-holder.stl
3.00 x 25.0 x 40.0

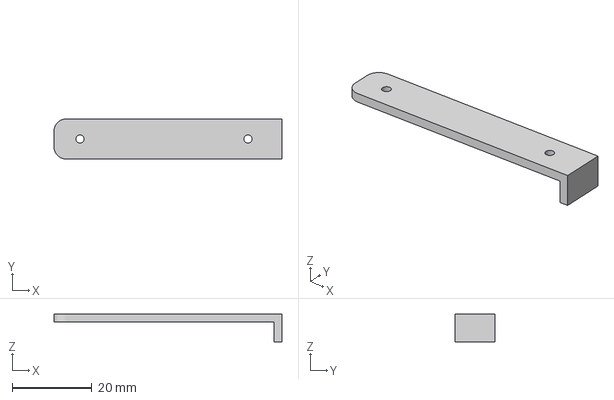
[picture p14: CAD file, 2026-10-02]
3d-models/fusion/kp8-table-holes-template.3mf
57.0 x 10.0 x 7.00 mm

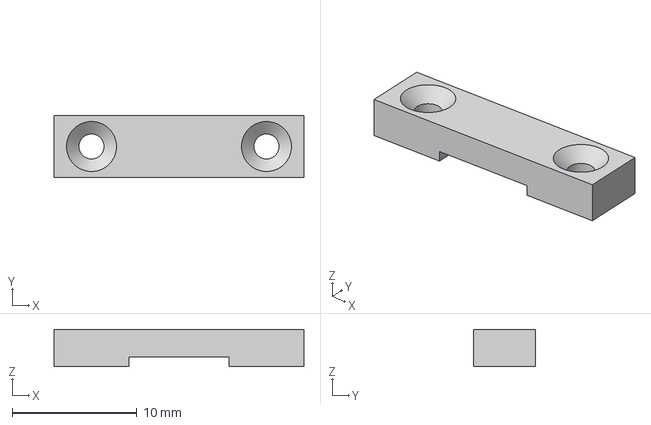
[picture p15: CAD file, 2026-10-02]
3d-models/fusion/encoder-wire-holder.3mf
20.0 x 5.00 x 3.00 mm

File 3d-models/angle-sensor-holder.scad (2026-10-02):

include <BOSL2/std.scad>
$fn = 130;

width = 25;
height = 40;
thickness = 3;

hole = 2.5;

diff() {
    cuboid([thickness, width, height], rounding = 3, edges=[FWD+TOP, TOP+BACK, BACK+BOTTOM, BOTTOM+FWD])

    tag("remove")
    position(BOT)
        ycopies(16) up(5)
        xcyl(l = thickness+2, d = hole);
}

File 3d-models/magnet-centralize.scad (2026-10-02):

include <BOSL2/std.scad>
$fn = 130;

shaft_d = 8.1;
magnet_d = 4.1;

thickness = .8;
length = 5;

diff() {
	cyl(l = length, d = shaft_d + 2*thickness)

	tag("remove") {
		position(BOT)
			up(thickness)
			cyl(l = length, d = shaft_d, anchor = BOT);

		position(BOT)
			up(thickness)
			cyl(l = length, d = magnet_d);
	}
}

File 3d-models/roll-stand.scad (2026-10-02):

include <BOSL2/std.scad>
$fn = 130;

height = 14;
length = 55;
width = 13;

hole = 5;

diff() {
    cuboid([length, width, height], rounding = 3, edges=[FWD+RIGHT, RIGHT+BACK, BACK+LEFT, LEFT+FWD]);

    tag("remove")
    xcopies(42)
        cyl(l = height+2, d = hole);
}

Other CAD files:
3d-models/sill-handler.scad
3d-models/fusion/motor-part.f3z
3d-models/fusion/table_template.f3d

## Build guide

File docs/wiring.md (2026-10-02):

# Wiring — RP2350 Supermini

Pin map for the whole rig, and what is actually connected today.

[desk-move-safe](../desk-move-safe) sits **in** the panel-TX wire — it does not
merely listen — so the two desk channels are wired differently from each other:
two pins in the cut keys wire, one wire tapping the height stream. Six signals
leave this board in total, three to the desk and three to the driver.

## The board

A 23.5 × 18 mm RP2350**A** module — same die as a Pico 2, so `PICO_BOARD pico2`
is correct, but the break-out is not the Pico's:

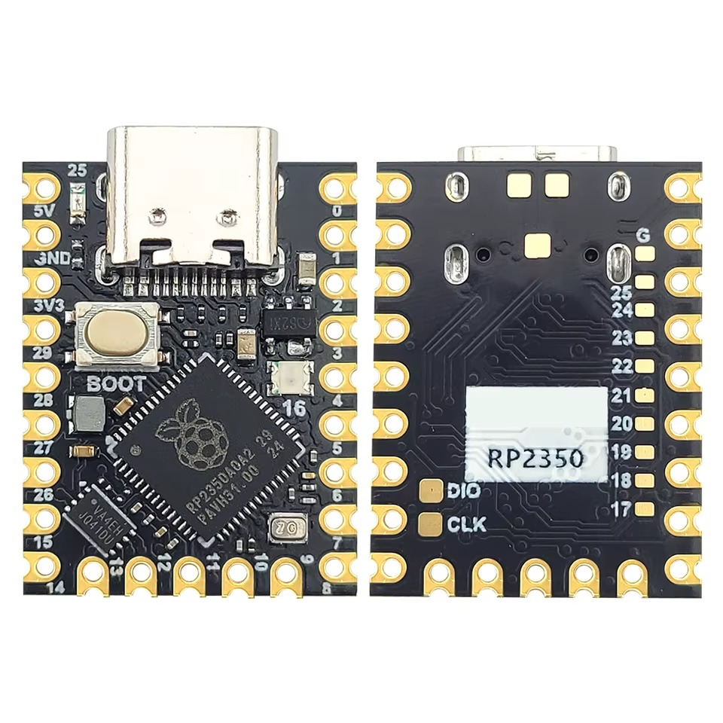
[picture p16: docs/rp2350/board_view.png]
front and back


| Edge | Pads (in order) |
|---|---|
| top-left | `5V` `GND` `3V3` |
| left | GP29 GP28 GP27 GP26 GP15 GP14 |
| bottom | GP13 GP12 GP11 GP10 GP9 GP8 |
| right | GP0 GP1 GP2 GP3 GP4 GP5 GP6 GP7 |
| back, inner row | `G` GP25 GP24 GP23 GP22 GP21 GP20 GP19 GP18 GP17 |

Three consequences that shape everything below:

- **GP16 is not free.** It drives the onboard WS2812 RGB LED. It is also the
  only LED on the board — there is no plain user LED — so it is worth keeping
  for status rather than reclaiming.
- **GP17–GP25 are back-side inner pads**, not castellations: small, close
  together, and awkward to solder to. Treat GP0–GP15 and GP26–GP29 as the
  usable set. That is still 20 pins for the 12 this rig needs.
- **There is exactly one GND pad on the front.** The desk tap, the driver
  logic, the encoder and the motor supply all need to reach it. Do not stack
  four wires on one castellation — run a short pigtail from `GND` to a screw
  terminal or a scrap of stripboard and make that the rig's ground node.

The vendor pinout image (`rp2350/board_pinout_top.png`) has typos — it swaps
SPI1 SCK/TX on GP14/GP15, and the back-side sheet is captioned RP2040. Where it
disagrees with the RP2350 datasheet, the datasheet wins. The assignments below
follow the datasheet.

## Pin map

| GP | Signal | Goes to | Wired |
|---|---|---|---|
| GP0 | UART0 **TX** | → panel RX — only if the height wire is ever cut | **no** |
| GP1 | UART0 **RX** | ← main board TX (`55 AA` height frames) | **yes** |
| GP2, GP3 | — | free | — |
| GP4 | UART1 **TX** | → main board RX — the board hears **only** this | **yes** |
| GP5 | UART1 **RX** | ← panel TX (`AA 55` key frames) | **yes** |
| GP6 | DIR | driver DIR | **yes** |
| GP7 | STEP | driver STEP | **yes** |
| GP8 | EN | driver EN (active low) | **yes** |
| GP9, GP10 | — | the driver's UART, if it is ever turned on (below) | no |
| GP11 | — | the driver's DIAG, or a limit switch | no |
| GP12–GP15 | — | free | — |
| GP16 | — | onboard WS2812: blinks red when the desk lock refuses a panel press (`led.c`, on `pio1`) | yes |
| GP26 | SPI1 SCK | MT6835 CLK | not yet |
| GP27 | SPI1 TX | MT6835 MOSI | not yet |
| GP28 | SPI1 RX | MT6835 MISO | not yet |
| GP29 | SPI1 CSn | MT6835 CS | not yet |

**GP0 is not connected**, and the firmware never claims it. The height stream is
tapped, not cut, so the board still drives the panel directly and there is
nothing for us to transmit into. It keeps its place in the map only so that
cutting that wire later needs no rewiring.

The desk side lives in
[desk-move-safe/include/board_config.h](../desk-move-safe/include/board_config.h),
and so does the flap motor; desk-lab (kept locally, not in this repo) is the instrumented rig
that the same map was worked out on.

The flap is one unbroken run. GP7 is the last pad of the right edge and GP8 the
first of the bottom, so **GP6–GP11 are six pads in a row** around the
bottom-right corner: DIR, STEP, EN, then the UART pair if it is ever wanted,
then DIAG. The driver harness is one connector.

**GP26–GP29 are four in a row** at the top of the left edge — the whole encoder
cable, as far from the driver corner as this module gets. CS lands on GP29 on
purpose: GP29 is ADC3 and carries a VSYS sense divider on many RP2350 modules,
and CS is an output, so a weak divider cannot affect it. A MISO there could be
pulled.

Two assignments differ from the earlier WeAct build, and both are forced:

- **The encoder moved GP16–19 → GP26–29.** GP16 is the RGB LED and GP17–19 are
  back-side pads, so the bench rig's SPI0 group is not reachable on this module
  at all. The RP2350's SPI functions repeat every eight pins as RX/CSn/SCK/TX,
  so GP26–GP29 is a complete SPI1 group — and it is the far corner from the
  driver, which is what the sensor cable wants.
- **The driver moved GP2/GP3/GP6 → GP6/GP7/GP8.** Three consecutive pads
  instead of two plus one stranded across the desk bus, and it leaves GP2/GP3
  free beside the desk pins.

## The desk: three wires, two channels, wired differently

The desk's 4-pin panel header is `3.3V RX TX GND`. 9600 8N1, 3.3 V logic
([protocol doc](CL103B-G_protocol.md) §1).

The two channels are not treated alike, and that asymmetry is the whole design:

```
  KEYS    panel ──> board     CUT, routed through us      TWO pins

     panel TX ──1k──> GP5  UART1 RX      we hear every key the panel sends
                              │
                             GP4  UART1 TX ──1k──> board RX
                                                   the board hears only us

  HEIGHT  board ──> panel     UNCUT, tapped in parallel    ONE pin

     board TX ──┬───────────────────────> panel RX     (untouched)
                └──1k──> GP1  UART0 RX                 (just listening)
```

**Cut a wire only to suppress what crosses it. Never to hear it.** A
UART RX pin is a high-impedance input, so any number of listeners can hang off a
line one thing drives — tapping the height stream costs the board nothing and
the panel nothing. The keys wire is cut because suppressing a key press is
exactly what this firmware is for.

| Panel pin | Actually carries | RP2350 | |
|---|---|---|---|
| `RX` | `AA 55` key frames, **panel → board** | GP5 in, GP4 out | **cut** |
| `TX` | `55 AA` height frames, **board → panel** | GP1 in | tapped |
| `GND` | ground | GND | |
| `3.3V` | panel supply | **not connected** | |

> ⚠️ **The panel's `RX`/`TX` labels are swapped.** Photographed on this desk's
> panel PCB: the pin marked `RX` is the one the panel **transmits** on. The
> labels name the main board's role, not the panel's — the board's own header
> is labelled by function and is not swapped.
>
> Getting this backwards puts both leads on the wrong pins at once, and the
> failure is silent in both directions while the desk carries on working
> normally. The same pin serves both roles: the wire you listen to and the wire
> you end up driving are both the one marked `RX`.

Rules, from [protocol doc](CL103B-G_protocol.md) §5:

- **Input pins only.** Never drive a line the panel or the board is already
  driving — two push-pull outputs on one wire corrupt frames and have been
  observed to freeze the panel. GP4 is the one output, and it is legitimate
  only because the panel's end of that wire has actually been cut; the firmware
  leaves it high-impedance until it has *heard* a frame from the panel, which
  is the cheapest available evidence that the cut is real. GP0 is never claimed
  at all.
- **1 k–10 k series resistor in every probe lead.** Invisible at 9600 baud, and
  it is what turns a wiring mistake into nothing happening.
- **Leave the header's 3.3 V pin alone.** It is the panel's supply, not a
  reference. Share ground only.

The board keeps reporting height with the tap in place because the tap changes
nothing electrically — it is one more high-impedance input on a line the board
was already driving.

## The stepper

TMC2209 carrier in the driver's standalone **STEP / DIR / EN** mode.

| Carrier | RP2350 | Note |
|---|---|---|
| VDD | 3V3 | logic supply. Not 5V — RP2350 GPIOs are not 5 V tolerant |
| GND (logic) | the ground node | must be common with the motor supply |
| DIR | GP6 | a level, sampled on the STEP edge |
| STEP | GP7 | rising edge = one microstep |
| EN | GP8 | **active low**: 0 = coils energised |
| MS1, MS2 | strapped | both low = 1/8 (see below) |
| VREF | the trimmer | **the current limit. Set it first.** |
| PDN_UART | leave unconnected | |
| VM, GND | 12–24 V PSU | |
| 1A 1B 2A 2B | motor | one coil per pair — ohm them out first |

GP6–GP8 are three consecutive pads wrapping the bottom-right corner (GP7 ends
the right edge, GP8 begins the bottom), so the driver is one connector. GP9 to
GP11 continue the run for the optional UART pair and DIAG.

### Microstepping is strapping, so the firmware has to be told

MS1/MS2 both low or floating is **1/8** on the TMC2209 — *not* the A4988 table,
and there is no full-step mode.

| MS2 | MS1 | microsteps |
|---|---|---|
| 0 | 0 | 1/8 ← power-on default |
| 0 | 1 | 1/2 |
| 1 | 0 | 1/4 |
| 1 | 1 | 1/16 |

`TMC_MICROSTEPS` in
[board_config.h](../desk-move-safe/include/board_config.h) must match how you
actually strapped it. Nothing detects a mismatch: every "revolutions" figure
the firmware prints, and later every travel limit, is simply off by that ratio,
silently.

### Set VREF before the first run

In this mode VREF **is** the current limit — the firmware cannot see it and
cannot change it. On a 0.11 Ω carrier, `I_rms ≈ 0.71 × VREF`.

Check the sense resistor while you are there: 0.10 Ω, 0.11 Ω and 0.15 Ω all
ship on boards sold under the same description, and it scales everything.

### The four rules that keep drivers alive

Unchanged from the [bench rig](../../test/nema_MT6835/docs/wiring.md):

1. **Never unplug the motor while VM is live.**
2. **≥100 µF electrolytic across VM/GND, physically at the driver.**
3. **Common ground** between the motor supply and the RP2350.
4. **Set VREF before the first run**, and re-calibrate StealthChop after any
   change to it.

If the flap travels the wrong way, invert it in software rather than swapping
motor wires: desk-lab has `FLAP_DIR_EXPAND` for exactly that, and
desk-move-safe gets the equivalent when the flap move itself is wired up.

### The UART option, and why it is off

The driver can also run on a serial link over its PDN_UART pin — built, working,
and switched off. `TMC_UART_ENABLED` in
[board_config.h](../desk-move-safe/include/board_config.h) turns it on, with
`TMC_USE_DIR_PIN` and `TMC_USE_EN_PIN` then free to move DIR and EN into
registers. GP9 and GP10 are reserved for it: TX through a 1 kΩ, RX on the same
node, joined at this board so one wire leaves for the driver.

What it buys: current and microstepping as numbers instead of a trimmer and
jumpers, over-temperature and open-coil reporting, StallGuard, and a wire count
of **two instead of three**.

What it costs, and why one wire did not pay for it here:

- **VM must be live before the chip will answer at all.** Logic power alone is
  silence, permanently, and the symptom is identical to a broken wire.
- **A solder jumper on the carrier ships unbridged.** Watterott
  SilentStepSticks need ["the jumper on the driver … bridged from the middle to
  the respective
  position"](https://learn.watterott.com/silentstepstick/pinconfig/tmc2209/);
  other boards have a pad marked `UART`/`USART` connected to nothing. Until
  that blob exists, correct wiring and correct firmware produce silence.
- **The 1 kΩ is not optional** — both ends drive the one pad.
- **MS1/MS2 become the UART address**, the same pins that used to pick
  microstepping. A driver on the wrong address is silent exactly like a driver
  that is not there.

Three pins that either work or visibly do not, against two pins plus four new
ways to be silently wrong. The firmware keeps both paths compiled, so this is a
one-line decision whenever the trade looks different.

> ⚠️ **desk-lab wants its own harness**, and the two are not
> interchangeable at the driver end:
>
> | | desk-move-safe | desk-lab |
> |---|---|---|
> | STEP | GP7 | GP2 |
> | DIR | GP6 | GP3 |
> | EN | GP8 | GP6 |
> | limit switch | GP11 | GP7 (`PIN_LIMIT`) |
> | MT6835 | GP26–29 | GP8–11 (reserved, unused) |
>
> Both run the driver standalone, so only the pin numbers differ — but they
> differ on every single one. Decide which board the flap harness belongs to
> before soldering it.

## Power

Bench work is **USB only**. You need the USB-CDC console anyway, and
the motor PSU stays a separate supply with its ground tied to the rig's ground
node.

For a permanent install, buck the 24 V down to 5 V and feed the `5V` pad. Then:
**one supply at a time.** There is no ORing diode between the `5V` pad and
VBUS on this module, so 5 V on that pad with USB also plugged in back-feeds the
host port. Unplug one before connecting the other, or put a Schottky in the
buck's output.

> ⚠️ **Do not power the flap driver (TMC2209 VM) from the controller board's
> power output port.** The board **cuts that output while the desk is moving**
> (confirmed with a meter, 2026-10-02) — it is switched, not wired straight to
> the supply input. Board photo: [desk/2026-09-22 10-49-11.JPG](desk/2026-09-22%2010-49-11.JPG).
>
> What it looks like from the firmware: the flap motor loses power mid-move,
> drops out of step and cannot recover at speed, so it shakes through the rest
> of the fast part and the flap then creeps the whole travel in 20–30 s
> (`[flap] STALL`). It only shows when the flap moves while the desk does —
> `mot_early_start 1`, or a `mot go` during a desk move — which made it look
> like a software fault.
>
> **Give VM a supply that stays on while the desk moves**: a separate 12–24 V
> adapter, or the desk's supply taken *before* the controller board. Share the
> ground with the RP2350.

The desk header's 3.3 V is not a candidate for powering the rig — it is sized
for a panel with an LCD and a few buttons, and a stepper driver's logic plus an
encoder on top of it is asking for a brown-out that takes the desk down too.

### Powered from the header's 3.3 V, USB will not enumerate

Observed 2026-10-02 on the dev board, with its `3V3` pin fed from the desk
header's 3.3 V. **The plugging order decides whether USB works:**

| Order | Result |
|---|---|
| desk powered first, then USB plugged in | no tty appears on the Mac |
| USB first (or desk power removed), then desk | tty appears and keeps working |

The cause is back-powering. 3.3 V fed into the **output** of the module's
regulator leaks backwards through it: the `5V`/VBUS pin measured **3.3 V
with no USB attached**. The host then finds voltage on a line only it should
drive, and does not enumerate. Once the host's 5 V is there first, the leak
has nothing to push against.

A diode between the header and `3V3` does **not** help — the leak path is
`3V3` → regulator → VBUS, downstream of it. The fixes are on the VBUS side:

- **Dev:** a USB cable or adapter with VBUS (red) cut. The host detects the
  device by the D+ pull-up, not VBUS, and the SDK forces VBUS-detect on
  modules with no sense pin, so data still works.
- **Board:** a Schottky in the VBUS line, anode at the connector — the
  Pico's VBUS → VSYS diode. Then any order works.
- **Plugging USB first** works, but leaves the module's regulator and the
  desk's fighting over one rail. Bench minutes only.

Under the desk nothing is plugged into USB, so production is unaffected — but
check the Supermini schematic for a VBUS diode before committing to a harness.
The concern above still stands: this is the panel's supply.

## Two RP2350 traps

**Erratum E9 — do not use internal pull-downs.** A GPIO configured as an input
with the internal pull-down enabled can latch at roughly 2.1 V after being
driven high, instead of returning to 0. Every input on this rig is therefore
pulled *up* and active-low: the limit switch, if you fit one, goes between the
pin and GND and reads LOW when pressed. If you ever genuinely need a
pull-down, make it an external resistor of 8.2 kΩ or less.

**GPIOs are not 5 V tolerant.** The desk bus is 3.3 V and so is the MT6835, so
nothing here violates that — but it is the reason the driver's VDD goes to 3V3
and not 5V, since its outputs swing to whatever you feed it.

## Later phases, wired ahead

Nothing below is needed to bring the rig up; it is here so the pin map does not
have to move again.

**In the wire** *(implemented, and described above)*. The RP2350 sits in the
broken panel-TX wire, between the panel and the board. The section below is why
the channels were grouped onto the UARTs the way they were.

### One UART per channel

The bus is two independent one-way channels, and each gets a whole UART —
receiving one end of its channel and transmitting the other, which is the
shape a UART already has:

```
  HEIGHT channel   board ──> panel     UART0    in GP1   out GP0
  KEY channel      panel ──> board     UART1    in GP5   out GP4
```

```
   main board  TX ──┬──────────────────────> panel RX        (untouched)
                    └──1k──> GP1  UART0 RX                   (just listening)

   panel       TX ──1k──> GP5  UART1 RX  ⟶  GP4 ──1k──> board RX
                                                             (cut, through us)
                          + shared GND
```

Grouping by channel rather than by device is what makes the harness fall out
right: the cut wire's two ends land on **GP4 and GP5, one adjacent pair, one
connector**, and the height tap is a single wire to GP1. GP0 is not needed
until the height channel is cut too.

The alternative — a UART per *device*, each carrying both directions of one
side — needs two UARTs to move one channel and puts the two halves of the cut
wire on opposite pin pairs.

> ⚠️ **Direction within a pair is forced, and this is the one that bites.**
> `GP0` and `GP4` are **TX — outputs, always**. `GP1` and `GP5` are **RX —
> inputs, always**. No setting reverses a pair, so a wire that needs listening
> to has to land on GP1 or GP5, and one that needs driving on GP0 or GP4.
>
> Get a pair backwards and the failure is silent in both directions at once:
> the input you wired to an output pin is fought by our driver and never
> received, and the output you wired to an input pin drives nothing — while
> the panel and board carry on over whatever path is left, so the desk still
> works and you look for the fault everywhere except the pins. `wiring` prints
> the direction of every pin next to what it has actually heard.

`SWAP_UARTS` in desk-lab's `board_config.h`
exchanges the two channels wholesale if the harness would rather have the cut
wire at the top of the right edge.

### What has to be cut

**Cut a wire only to suppress what crosses it. Never to hear it.**

A UART RX pin is a high-impedance input, so any number of listeners can hang
off a line that one thing drives. Tapping costs the driver nothing and the
other listeners nothing.

That settles both wires at once:

| wire | what we need | cut? |
|---|---|---|
| panel TX → board RX | to be able to **stop** the panel's commands | **yes** |
| board TX → panel RX | only to **read** the height | no — tap it |

So exactly one wire is cut, and its two ends land separately: the panel's on
GP5 and the board's on GP0. The height line stays whole, with GP1 hanging off
it through a 1 k resistor alongside the panel — which is why the panel's
display keeps working no matter what this firmware does.

The `board TX → panel RX` direction is a choice, `PROXY_HEIGHT_TO_PANEL`:

| | wires | panel's display |
|---|---|---|
| `0` | 3 signal | fed straight from the board; works whatever the firmware does |
| `1` | 4 signal | fed by us, forwarded byte for byte |

**`0` is the default**, and the right starting point: the panel's display then
works regardless of what the firmware does, which takes a whole class of
failure out of the picture while the rest is being proven. GP4 stays high-Z
and unused. Move to `1` only once there is a reason to shape what the panel
is told, and only after cutting that wire — claiming GP4 while the board is
still driving the panel's RX line is two outputs on one wire. Forwarding is **raw**, not re-encoded from a decoded
height: the field carries flag bits that are only partly understood and the
board may send types this firmware does not decode, so passing the bytes means
a gap in our decoding cannot become a gap in the panel's display.

Keep a 1 kΩ series resistor in every lead, transmit legs included.

### Two safety properties that come from being in the path

**It fails safe.** A desk that is told nothing stops moving. If the firmware
hangs, resets or is unplugged, no key frames reach the board — so the failure
mode of a cut wire is a stationary desk, not a runaway one.

⚠️ **The corollary: a board that is not proxying is a desk that cannot move at
all.** So `PROXY_ON_BOOT` is `1` — the firmware boots straight into
pass-through and the panel drives the desk as it always did. Leave it that
way; with it off, a reset or a reflash locks you out of your own furniture
until you can find a terminal.

Proxying is transport, not control. Taking the desk away from the panel is a
separate switch (`take`, or the intercept firing), and neither is on by
default.

**The ceiling is a guarantee, not a threshold.** `DESK_CEILING_MM` is enforced
in the relay, so an UP command that would carry the desk past it is replaced
with idle — whatever the panel asks, including a button held down, and
whatever any other part of this firmware gets wrong. Enforced `DESK_COAST_MM`
early so the coast lands *at* the limit rather than past it.

### The uncut fallback

`DESK_WIRING_CUT 0` restores the earlier arrangement: panel unplugged, GP5
doing double duty as UART1 RX while sniffing and a PIO transmitter
(desk-lab's `src/uart_tx.pio`) while emulating — GP5's only
hardware UART function is RX, so a transmitter there has to be PIO. No relay
is possible in that mode; there is no break in the wire to relay through.

**Phase 3 — the encoder.** MT6835 breakout, bottom (SPI) header only; the top
header (A/B/Z, U/V/W, PWM) and HVPP stay empty.

| MT6835 | RP2350 | |
|---|---|---|
| VCC | 3V3 | |
| GND | the ground node | |
| CLK | GP26 | SPI1 SCK |
| MOSI | GP27 | SPI1 TX |
| MISO | GP28 | SPI1 RX |
| CS | GP29 | SPI1 CSn, driven by hand |

1 MHz bus. The magnet must be **diametrically** magnetised, 0.5–3 mm above the
package and centred on the shaft axis — that mounting, and how to check it, is
the long half of the [bench rig's wiring
doc](../../test/nema_MT6835/docs/wiring.md).

**Both UARTs are spoken for**, so the TMC2209's own link is a PIO UART — written
and working, switched off, on GP9/GP10. See "The UART option, and why it is off"
above; none of it affects motion either way.

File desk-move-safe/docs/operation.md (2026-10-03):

# Operation

## What it does

The panel is in charge. Every key frame it sends is forwarded to the main
board unchanged, and the height comes back to the panel directly over a wire
this firmware does not touch — so the display works whatever happens here.

Two things change that.

**The ceiling.** An UP command that would carry the desk past `DESK_CEILING_MM`
is replaced with idle. Because the firmware is in the path, that is a
guarantee rather than a request: it holds against a button held down, and
against any other part of this firmware getting it wrong. A held UP is refused
a coast early (it runs on ~18 mm after release); a tap only if its 10 mm step
would end past the ceiling, so single taps reach 79.x cm under an 80 cm
ceiling. A refusal prints `[desk] UP refused at … — the ceiling is …` and
blinks the LED red. Preset recalls are not checked against it.

**The flap height.** A move that would carry the desk past it is stopped
there, the flap runs, and the move then continues to where it was going.

## How a preset is handled

A preset recall announces its destination about a second *before* the desk
moves, so the whole move is known in advance — there is no need to watch the
desk approach and try to stop it in time.

Once a preset's height has been seen, the recall is **not forwarded at all**.
The board never starts, there is nothing to abort, and nothing can overshoot a
height it has not begun travelling towards. The move is driven from here to the
flap height, and finished by re-issuing the recall, so the board lands on its
own stored height exactly and the user gets the position they asked for.

That re-issued recall is **one frame**, because that is what the code means to
the board: a real panel press puts `0x01` on the wire for a single frame and is
idle again on the next poll. Sent for two or three frames it is a button being
held, and the second frame cancels the recall the first one just started — the
desk sets off, travels about a centimetre and stops there. It survived some of
the time, depending on where the extra frame landed in the board's second of
start-up latency, which is exactly what an intermittent fault looks like.

The first press of each preset is the exception: its height is unknown, so the
recall is forwarded, the announcement is read, the desk is stopped, and the
height is learned and written to flash. Every press after that — including
after a reset — is the clean path. `eeprom set panel_stand_mm 803` skips even that.

**The presets are the only settings stored automatically**, and only when
they really change:

1. At startup the stored stand and sit heights are read once.
2. Every stand or sit recall that reaches the board is watched for *its own*
   announced destination — one that arrives after the recall. (The board's
   previous announcement is still held and must not be mistaken for it; that is
   how stand was once learned as the sit height.)
3. The announced height is compared with the stored one. **Different:**
   `[flap] preset stand: 803 -> 805 mm — stored`, written to flash once the
   desk is still. **Same:** nothing is written.
4. Saving a preset on the panel writes nothing either.
   The preset is only marked untrusted — no takeover relies on it — until its
   next recall, which either confirms it (`confirmed … nothing written`) or
   stores the new height.

This happens in dev mode, with the flap off and right after a flap move alike;
watching changes nothing on the bus. A recall issued while the desk is already
at that preset is not announced, so it teaches nothing.

Everything else is written only when asked: `eeprom set`, `calibrate`, `lim`,
`reset`. One exception, after a firmware update: a record in an older layout
is rewritten in the new one.

**Whether the desk is stopped at all is read off the flap itself.** Above the
flap height the flap must be collapsed, below it expanded. A move heading across
is stopped only if the flap is not already at the end that side needs (the
encoder says, to within 3°) — however the desk got there, and with no memory of
earlier crossings to go stale.

**The crossing guard.** One thing must never happen: the desk above the flap
height with the flap not collapsed. The intercept above normally prevents it by
moving the flap. Where it does not act — `desk_flap_on 0`, dev mode, the
hands-off window after a flap move — a guard does, the same way the ceiling
works: a held UP, a tap or a preset recall that would carry the desk **up
across the flap height while the flap is not collapsed** is replaced with idle.
The console prints `[flap] REFUSED: going up past … with the flap not
collapsed`, the LED blinks red, and `desk` counts the refusals. A recall whose
height was never learned is refused too, since it cannot be judged. `go` refuses
the same move and says to run `mot go collapsed` first. Going **down** is never
refused: a collapsed flap below the flap height is out of the way.

**The flap height has a safe gap**, `FLAP_SAFE_GAP_MM` (20 mm): it is chosen
with room to spare, so anywhere within 2 cm past it still counts as "at the
flap height". A desk that landed there with the flap not yet set for the side it
is asked to go to — a stop a few millimetres long, or a flap move that failed —
gets the flap moved on the next press, right where it stands
(`[flap] at the flap height (… mm) with the flap not collapsed — moving it`).

**Further up than that** with the flap not collapsed — however it came about —
the desk may not go higher: every UP and every recall that does not lead down
is refused, with the same red blinks. Down is the way out; so is
`mot go collapsed`. The same applies inside the gap when the flap stop is off
or suspended, since nothing will move the flap then.

So with `desk_flap_on 0` the desk is not free to roam: it stays on the side its
flap allows, until the flap is moved by hand (`mot go collapsed`) or the flap
stop is switched back on.

A **held** up/down press has no announcement, since nobody knows where the user
will let go, so that one is stopped as it approaches. Then the flap moves, and
the bus goes back to the panel (`[flap] a held move — the flap, then the panel
has it back`): keep holding, or press again, and the desk carries on.

A **recall that slipped past the takeover** — pressed during the hands-off
window after a flap move, say — is still stopped as it approaches, and then
treated as the takeover would have treated it: the flap runs and the recall is
sent again to finish the move (`[flap] it is a recall to … — the flap, then the
recall again`). Before 2026-10-02 it was stopped like a held press and left
there, so the desk stayed at the flap height.

A **tap** of up/down is a fixed 10 mm step that ends by itself, and the only
way to stop one is a tap the other way — which is a step back. So a tap is
judged by where it will end, not by how close it gets:

- ending short of the flap height: left alone, however close it gets;
- ending past it, with the flap not yet at the end that side needs: **not
  sent** — the flap is moved instead, the desk standing where it is
  (`[flap] a step from … would pass … — moving the flap first`). The next tap
  finds the flap in place and goes through. If the press was the start of a
  hold, the desk sets off once the flap has moved.

Until 2026-10-02 a manual crossing never moved the flap: a second tap simply
went through, and a held move was stopped and released, so the desk could be
walked past the flap height with the flap still expanded.

Before this, a tap from 742 mm toward a flap at 770 was "stopped" at 752 with a
down tap, and the desk stepped straight back to 742.

## Working mode and dev mode

**A reset always produces working mode.** There is no stored mode, no jumper and
no boot flag — the mode is a static bool that reset zeroes. A mode that can be
stored is a mode a board can be left in, and the board that gets left in it is
always the one nobody is watching.

At boot the firmware asks three questions, and `dev` or `status` repeats them:

| check | what it means |
|---|---|
| `driver` | can the stepper driver be reached — only askable over UART |
| `encoder` | does the MT6835 answer |
| `limits` | are both ends stored in flash |

A check can say **`not in this build`**, which is not a failure. "Not built" and
"broken" need different reactions, and collapsing them into one bool is how a
firmware ends up refusing to work because of a feature nobody has written yet.

**A failed encoder or limits check locks the desk.** The flap sits in the
desk's path, and a flap left open is in the way: until the firmware can see the
flap and knows where its ends are, it cannot tell whether a move is safe. So
every UP, DOWN and preset recall — from the panel or from `go` — is replaced with
idle, the board's LED blinks red at each refused press, and `status` shows
`DESK LOCKED` and why. A stuck desk is the cheaper
failure. Decided 2026-10-02 while the flap is being fitted; the earlier rule
(switch the flap off and let the panel drive) may return once the flap is in
use. The driver check does not lock the desk — in standalone mode it cannot be
asked. [commands.md](commands.md#what-it-needs-to-move) lists exactly what it needs and how to calibrate; `reset` clears just that.

The same checks gate the flap move itself — and with a UART-linked driver, the
driver check too (`FLAP_DRIVES_MOTOR`, 1 since 2026-10-02).

### `dev start`

Unlocks the commands that drive something directly, poke at a register or
change the flap's stored range: `mot`, `tmc`, `enc`, `lim expanded`/`collapsed` and the
rest of `lim`, `go`, and `eeprom set` for the `lim_*`, `mot_*` and `desk_resume_pct`
parameters. Everything an installer needs — `status`, `calibrate`, `reset`, `desk`, `debug`,
`eeprom` and `eeprom set` for the `panel_*` and `desk_*` parameters, `lim`,
`stop` — stays available in working mode, because
working mode is not a reduced console, it is the console for a board doing its
job.

Dev mode also **suspends the flap intercept**, for the same reason a failed check
does, from the other side: someone hand-driving the motor must not have the desk
take the bus out from under them because a preset was pressed in the next room.
Entering is refused mid-sequence; leaving stops the motor and releases it.

It is gone at the next reset.

## Console (USB CDC)

Every command, with what it does and which mode it needs:
**[commands.md](commands.md)**. `?` on the board prints the short list; the
build fails if the two disagree.

### What is stored in flash

The preset heights, both coast figures, the flap height and whether the flap
stop is enabled, the flap's calibration (the angle at each end and two
directions, backlash, approach), the flap motor's speed, and the two timing
choices — when the flap starts (`mot_early_start`) and when the desk moves on
(`desk_resume_pct`) — one CRC-checked record
in the last flash sector, restored at boot before the bus runs. `eeprom` lists
every field; [commands.md](commands.md#parameters-explained) explains each one.

Written once the settings have been untouched for a couple of seconds **and
the desk has been still for three**: no height change and no move key or recall
sent, whoever started the move — a flash write blanks interrupts for tens of
milliseconds. Before 2026-10-02 only the firmware's own moves held it off, so a
recall passed to the board could be interrupted by a save at mid-height.

Not stored, and from `board_config.h` every boot: proxying (always on), the
ceiling switch, `mot accel`, and the protocol constants.

## Bring-up

1. Wire it per [../../docs/wiring.md](../../docs/wiring.md) — **one cut wire**,
   and mind the swapped `RX`/`TX` labels on the panel.
2. Power up with a terminal attached. `status` should show a live height and
   frames on both lines.
   - `NOT TRANSMITTING` means the panel has not been heard, so GP4 is still
     high-Z and the desk cannot move. Check the ground first: one missing
     ground leaves both lines silent while the panel and board still talk to
     each other perfectly.
   - `height never seen` with the panel heard means GP1 is on the wrong pin.
3. **Calibrate the flap, or the desk will not move:** `calibrate`, and follow it —
   jog the flap to expanded, `done`, to collapsed, `done`. `status` should no longer say
   `DESK LOCKED`. [commands.md](commands.md#calibrating) has the detail.
4. `eeprom set panel_stand_mm <mm>` and `eeprom set panel_sit_mm <mm>` if you
   know them — otherwise press each one once and let it learn.
5. `eeprom set desk_flap_mm 770` for the height, `eeprom set desk_flap_on 1`,
   and try a preset each way.

## Tuning

Coast (`desk_coast_up_mm`, `desk_coast_down_mm`) is how far the desk keeps
moving after being told to stop, so a stop meant to land at a height is sent
that much early — [commands.md](commands.md#parameters-explained) has a picture.
It is not the same in both directions, and it does not need to be exact —
anything that lands inside `DESK_NEAR_MM` (10 mm) of the mark is close enough,
and stopping *short* is the safe side, since the flap then runs before the desk
has crossed.

`go` reports where it actually landed, which is the number to tune against.

## Silencing the beep

The desk beeps once for every one-shot code it accepts, which is unavoidable
on the wire — but the buzzer can be turned off in the desk itself. On the
panel: hold `▼ + ▲` for 5 s, step to **`P06`**, press the **stand** button to
enter, set it to **0**, press **stand** to confirm. Alarms still sound.

Full parameter menu: [../../docs/CL103B-G_protocol.md](../../docs/CL103B-G_protocol.md) §8.

## The flap move

The flap has two ends, set by `calibrate`: **expanded** and **collapsed**. Below the
flap height (`desk_flap_mm`) it is expanded; above it, collapsed. So when a
move crosses the flap height:

| Desk going | Flap moves to |
|---|---|
| up (e.g. sit → stand) | COLLAPSED |
| down (e.g. stand → sit) | EXPANDED |

The direction comes from where the desk is headed — the recall's destination.
Without one (a recall caught late, whose height was never learned) the flap goes
to whichever end it is further from.

**When the flap starts is a stored parameter, `mot_early_start`.** 0 (the
default): once the desk has stopped at the flap height. 1: the moment the desk
is told to stop, so its coast and the flap's travel overlap and the crossing is
about a second shorter. 1 needs the flap driver on a supply that stays on while
the desk moves — the controller board's power output is cut during a move, which
stalled the motor (2026-10-02).
[commands.md](commands.md#when-the-flap-starts-mot_early_start) has the detail.

[`../src/flap_task.c`](../src/flap_task.c) moves the flap like `mot go`:
range-checked, fast to within `lim_approach_deg` of the end, then crept onto it
under the encoder, with the guard watching
([commands.md](commands.md#how-mot-go-arrives)). The console prints
`[flap] moving the flap to COLLAPSED`, then, once the flap is still,
`[flap] COLLAPSED (+0.05 deg from the end)` — and only
then is the recall re-sent to finish the desk's move. If the desk does not
reach the flap height (stalled, could not be stopped, `stop`), the flap move is
stopped too.

**When the desk moves on is a stored parameter too, `desk_resume_pct`.** 100
(the default): once the flap has settled on its end. Below 100: once the flap
has covered that share of its move, by the encoder, so the desk sets off while
the flap finishes. A flap that then fails can no longer hold the desk back.
On this desk it gains almost nothing: at 5000 steps/s with `mot_early_start 1`
the flap is 93–99% done by the time a recall may go, so 100 is the setting.
The recall only ever goes to a desk that has been still for 1.2 s — one sent
during the board's final crawl is dropped — and if the desk has not set off
4 s later it is sent once more.
[commands.md](commands.md#when-the-desk-moves-on-desk_resume_pct) has the detail.

**If the flap does not get there** — the move is refused, times out after
`FLAP_MOVE_TIMEOUT_MS` (20 s), `stop` is typed, or it does not settle within
0.1° — **the desk stays at the flap height** and the recall is not re-sent: the
flap is somewhere in the desk's path, and moving on could hit it. The console
says `FLAP MOVE FAILED`, the LED blinks red, and the panel has the desk back.
`lim` says where the flap actually is.

A flap that only gets there by creeping the whole way is reported as
`[flap] STALL` ([commands.md](commands.md#motor-speed-mot_speed_sps)).

The motor is left energised after a move, holding the flap where it is.

`FLAP_DRIVES_MOTOR 0` in `board_config.h` brings back the two-second dwell that
stood in for the move, for bench work on the desk side alone.

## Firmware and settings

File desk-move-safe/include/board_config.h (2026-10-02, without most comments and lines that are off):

#pragma once
#define UART_HEIGHT         uart0
#define PIN_FROM_BOARD      1       // <- board TX: 55 AA height frames (tap)
#define UART_KEYS           uart1
#define PIN_FROM_PANEL      5       // <- panel TX: AA 55 key frames
#define PIN_TO_BOARD        4       // -> board RX: what the board is told
#define DESK_BAUD           9600
#define DESK_POLL_MS        104     // the panel's poll period
#define PROXY_ON_BOOT       1
#define DESK_HEIGHT_MASK        0x3FFFu
#define DESK_HEIGHT_SANE_MIN_MM 200     // rejected outright outside this
#define DESK_HEIGHT_SANE_MAX_MM 2500
#define DESK_HEIGHT_STALE_MS    2000    // older than this: act on nothing
#define DESK_MAX_STEP_MM        10
#define DESK_ANNOUNCE_MAX_FRAMES 20     // ... unless it keeps saying so
#define DESK_DIR_STALE_MS       600     // no change for this long = stopped
#define DESK_MIN_MM             730
#define DESK_MAX_MM             1220
#define DESK_COAST_UP_MM        18
#define DESK_COAST_DOWN_MM      19
#define DESK_NEAR_MM            10
#define DESK_MOVE_TIMEOUT_MS    40000
#define DESK_STALL_MS           1500    // height stopped changing while driving
#define DESK_CEILING_MM         800
#define DESK_CEILING_ON         1
#define FLAP_DRIVES_MOTOR   1
#define FLAP_HEIGHT_MM          770
#define FLAP_ON                 1
#define FLAP_SAFE_GAP_MM        20
#define FLAP_REARM_MM           25
#define FLAP_SETTLE_MS          700
#define FLAP_FRESH_MS           350     // a height older than this is not evidence
#define FLAP_START_WITH_STOP    0
#define FLAP_MOVE_TIMEOUT_MS    20000
#define FLAP_MOVE_MS            2000
#define DESK_NUDGE_MM           10      // one edge frame, measured
#define DESK_NUDGE_LATENCY_MS   1000    // before it acts
#define FLAP_STOP_PHASE_MS      5000    // > latency + the ~3 s abort coast
#define FLAP_STOP_TRIES         3
#define FLAP_BRISK_MS           250     // still changing this recently = not braking
#define WIRE_ONESHOT_TIMEOUT_MS 1000
#define PLAN_RESUME_QUIET_MS    2000
#define PLAN_RESUME_MIN_MS      4000    // never sooner: the board takes ~1 s to start
#define PLAN_RESUME_MAX_MS      45000
#define PRESET_STAND_MM         0
#define PRESET_SIT_MM           0
#define PIN_DIR             6       // sampled by the driver on the STEP edge
#define PIN_STEP            7       // rising edge = one microstep
#define PIN_EN              8       // active LOW: 0 = coils energised, 1 = free
#define PIN_TMC_DIAG        11
#define TMC_MICROSTEPS      8
#define TMC_UART_ENABLED    0
#define TMC_USE_DIR_PIN     1
#define TMC_USE_EN_PIN      1
#define TMC_UART_ADDRESS    0
#define PIN_TMC_TX          9
#define PIN_TMC_RX          10
#define TMC_UART_PIO        pio0
#define TMC_UART_BAUD       115200  // the chip works it out from the sync byte
#if !TMC_UART_ENABLED && (!TMC_USE_DIR_PIN || !TMC_USE_EN_PIN)
#error "With TMC_UART_ENABLED 0 there are no registers to put direction or \
enable in, so TMC_USE_DIR_PIN and TMC_USE_EN_PIN must both be 1. Either wire \
the pins, or turn the UART back on."
#endif
#define MT6835_SPI_PORT     spi1
#define MT6835_PIN_SCK      26      // SPI1 SCK
#define MT6835_PIN_MOSI     27      // SPI1 TX
#define MT6835_PIN_MISO     28      // SPI1 RX
#define MT6835_PIN_CS       29      // SPI1 CSn, driven by hand
#define MT6835_SPI_BAUD     (1000 * 1000)
#define ENCODER_NOISE_FLOOR_DEG 0.05
#define POSITION_TOLERANCE_DEG  1.0
#define LIMIT_GUARD_DEG     1.0
#define LIMIT_RESYNC_DEG    1.0
#define LIMIT_SETTLE_DEG    0.1
#define LIMIT_APPROACH_DEG  4.0
#define FULL_STEPS_REV      200     // standard 1.8 deg NEMA 17
#define GEAR_RATIO          17.23
#define TMC_RSENSE_OHMS     0.11
#define TMC_MAX_CURRENT_MA  1500    // refused above this, whatever is asked
#define TMC_RUN_CURRENT_MA  800
#define TMC_HOLD_CURRENT_MA 300
#define TMC_IHOLDDELAY      6       // how gradually it drops to hold current
#define TMC_TPOWERDOWN_TICKS 20     // ~0.4 s of standstill before it does
#define TMC_TOFF            3
#define TMC_TBL             2
#define TMC_HSTRT           5
#define TMC_HEND            0
#define DEFAULT_SPEED_SPS   5000u
#define DEFAULT_ACCEL_SPS2  30000u
#define PIN_LED             16
#define LED_PIO             pio1
#define LED_ORDER_GRB       1       // most WS2812s; 0 if "red" comes out green
#define LED_BRIGHTNESS      40      // of 255 — these are bright at arm's length
#define SETTINGS_QUIET_MS       2000
#define SETTINGS_ENABLE_FLASH   1

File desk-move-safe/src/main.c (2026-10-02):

//
// desk-move-safe — RP2350 firmware that keeps a desk from carrying a folding
// flap past the height it has to be moved at.
//
// It sits in the cut panel-TX wire between the desk's control panel and its
// CL103B-G main board, and forwards both directions. The panel drives the desk
// exactly as it did before. When a move would take the desk past the flap
// height, this takes the bus, stops it there, runs the flap, and lets the move
// finish.
//
//   bus_task      drains both UART taps, parses frames, decides   bus.c
//   wire_task     claims the transmit pin once the panel is heard wire.c
//   flap_task     stop / flap / continue                          flap_task.c
//   console_task  USB-CDC shell                                   console.c
//   encoder_task  MT6835 angle -> continuous shaft position       encoder.c
//
// The flap itself is a NEMA 17 on a TMC2209 in standalone STEP/DIR/EN mode:
// step pulses out of an alarm ISR (stepper.c), current from the carrier's
// trimmer, microstepping from its jumpers. The driver can be put on a serial
// link instead (tmc2209.c, off by default) — see docs/flap-motor.md for what
// that trade looks like.
//
// The decision itself is in flap.c, called from the bus task as each panel
// frame completes — nothing between the panel and the board is faster.
//
// Protocol and wiring: ../docs/CL103B-G_protocol.md, ../docs/wiring.md.
// The rig this was worked out on, with all the instrumentation: ../desk-lab.
//
#include <stdio.h>

#include "pico/stdlib.h"
#include "FreeRTOS.h"
#include "task.h"

#include "board_config.h"
#include "bus.h"
#include "wire.h"
#include "flap.h"
#include "console.h"
#include "settings.h"
#include "stepper.h"
#include "tmc2209.h"
#include "encoder.h"
#include "limits.h"
#include "led.h"

TaskHandle_t g_task_bus, g_task_wire, g_task_flap, g_task_console, g_task_encoder;

// A blown stack or a failed assert used to be a silent hang. Both say what
// happened before stopping.
void vApplicationStackOverflowHook(TaskHandle_t task, char *name)
{
    (void)task;
    printf("\n\n*** STACK OVERFLOW in task '%s' ***\n", name ? name : "?");
    for (;;) { }
}

void vAssertCalled(const char *file, int line)
{
    taskDISABLE_INTERRUPTS();
    printf("\n\n*** FreeRTOS assert: %s:%d ***\n", file, line);
    for (;;) { }
}

static void wait_for_serial(uint32_t timeout_ms)
{
    for (uint32_t t = 0; t < timeout_ms && !stdio_usb_connected(); t += 10)
        sleep_ms(10);
}

int main(void)
{
    stdio_init_all();

    // EN high and the coils off BEFORE anything that can block, so a board
    // that sat in BOOTSEL with floating pins does not come back energised and
    // then wait three seconds for a USB handshake while it does. With the
    // UART enabled instead of the EN pin this stops being tidiness and becomes
    // the only thing holding the driver off, so the ordering stays either way.
    //
    // Anything printed in here lands in a window no terminal is open for yet.
    // That is what the console's repeated banner is for, and 'tmc' and 'mot'
    // say all of it again on demand.
    stepper_init();
    bool motor = tmc2209_init();
    led_init();

    wait_for_serial(3000);

    // Learned presets and tuning from flash BEFORE the bus runs, so the first
    // press after a reset is already the clean, suppressed one.
    settings_load();
    printf("\n[boot] settings %s\n",
           settings_stored() ? "restored from flash"
                             : "from board_config.h (nothing stored)");
    limits_init();             // the flap range lives in the same record
    printf("[boot] flap motor %s\n",
           motor ? "ready" : "NOT available — 'tmc' for what to check");

    // Working mode, every time, and nothing here has to arrange that: the mode
    // lives in a static bool that reset zeroes, and it is never stored. The
    // self-check is evaluated on demand rather than latched at boot, so there
    // is nothing to run here either — the console's banner prints it a moment
    // from now, 'dev' repeats it, and flap_decide() consults it every frame.
    //
    // Nothing here blocks on the result. No encoder or no stored range locks
    // the DESK — flap_decide() refuses every move — because a flap left open is
    // in its path. See mode.h.

    // Bus highest: it is the only task with a hard deadline. A UART RX FIFO is
    // 32 bytes, which at 9600 baud is 33 ms of slack, and the console below it
    // can busy-wait for half a second inside a printf when the USB host stops
    // reading. It costs almost nothing to give priority to — it sleeps 5 ms
    // out of every 5 ms and moves a few bytes.
    //
    // Console next: it is the only way to say "stop". Then the wire task,
    // which only watches for the panel to appear, and the flap task, whose
    // moves are paced by the panel's own polling.
    xTaskCreate(bus_task,     "bus",     1024, NULL, 4, &g_task_bus);
    xTaskCreate(console_task, "console", 2048, NULL, 3, &g_task_console);
    xTaskCreate(wire_task,    "wire",     512, NULL, 3, &g_task_wire);
    xTaskCreate(flap_task,    "flap",    1536, NULL, 2, &g_task_flap);

    // Encoder alongside the console rather than above it: its SPI transaction
    // is 50 us and bounded, but a shell that cannot be heard is worse than a
    // sample that arrives late. It is below the bus task for the same reason
    // everything is — the bus is the only one with a hard deadline.
    xTaskCreate(encoder_task, "encoder", 1024, NULL, 3, &g_task_encoder);

    // Lowest: it only blinks.
    xTaskCreate(led_task,     "led",      256, NULL, 1, NULL);

    vTaskStartScheduler();

    printf("FATAL: scheduler did not start\n");
    for (;;) { }
}

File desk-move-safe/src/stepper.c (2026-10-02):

//
// stepper — step-pulse generation and the Austin/AVR446 acceleration ramp.
// See stepper.h for the algorithm and the API contract.
//
// Structure: one hardware alarm reschedules itself. Each firing emits a STEP
// pulse and then computes the interval until the next one. Nothing about the
// ramp lives in a task, so a busy task or a long printf can't stutter the
// motor — the ISR keeps the pulse train going on its own.
//
#include "stepper.h"
#include "tmc2209.h"

#include "pico/stdlib.h"
#include "hardware/timer.h"

#include "FreeRTOS.h"
#include "task.h"

#include <math.h>

// ---- hardware limits -----------------------------------------------------
#define STEP_PULSE_US   2u          // STEP high time; the TMC2209 needs >=100 ns
#define DIR_SETUP_US    2u          // DIR settle before the first edge (>=20 ns)
#define MIN_STEP_US     25u         // 40 kHz ceiling — past here the ISR can't keep up
#define MAX_STEP_US     100000u     // 10 steps/s floor; slower is a stall, not a move

// ---- profile limits ------------------------------------------------------
#define MIN_ACCEL       10u
#define MAX_ACCEL       10000000u   // high enough that d0 clamps to d_min: a hard start

typedef enum { M_IDLE, M_MOVE, M_RUN, M_STOP } mode_t;

// Owned by the ISR once a move starts; the API only touches them inside a
// critical section (the alarm IRQ runs below configMAX_SYSCALL_INTERRUPT_
// PRIORITY, so taskENTER_CRITICAL genuinely masks it).
static volatile mode_t   s_mode = M_IDLE;
static volatile int32_t  s_pos;             // signed microsteps since the last zero
static volatile uint32_t s_pos_gen;         // see stepper_pos_gen()
static volatile int32_t  s_n;               // Austin's counter; < 0 while decelerating
static volatile uint32_t s_d;               // current step interval, us
static volatile int32_t  s_rest;            // carried remainder of the recurrence
static volatile uint32_t s_remaining;       // steps left in an M_MOVE
static volatile int8_t   s_dir = 1;
static volatile TaskHandle_t s_waiter;

// Derived from the profile, recomputed at the start of each move.
static uint32_t s_d0;                       // first-step interval
static uint32_t s_d_min;                    // interval at the speed limit
static uint32_t s_sps   = DEFAULT_SPEED_SPS;
static uint32_t s_accel = DEFAULT_ACCEL_SPS2;

static bool s_enabled;
static int  s_alarm = -1;
static absolute_time_t s_next;              // the target we last armed

// ---- profile -------------------------------------------------------------

// d0 is the exact interval of the first step of a ramp: the time to cover one
// step under constant acceleration from rest, times Austin's 0.676 correction
// for the error the discrete recurrence accumulates early on.
static void recalc(void)
{
    double d0 = 0.676 * 1e6 * sqrt(2.0 / (double)s_accel);
    s_d0 = (d0 > (double)MAX_STEP_US) ? MAX_STEP_US : (uint32_t)d0;

    s_d_min = 1000000u / s_sps;
    if (s_d_min < MIN_STEP_US)
        s_d_min = MIN_STEP_US;

    // A ramp that would start slower than it ends is not a ramp; a d0 at or
    // below d_min means "jump straight to full speed" (see the demo's no-ramp
    // case, which is exactly how you provoke a stall).
    if (s_d0 < s_d_min)
        s_d0 = s_d_min;
}

// ---- alarm ---------------------------------------------------------------

// Schedule the next edge relative to the target we last armed, not to "now", so
// IRQ latency doesn't accumulate into audible jitter.
static void arm(uint32_t delay_us)
{
    s_next = delayed_by_us(s_next, delay_us);
    if (hardware_alarm_set_target((uint)s_alarm, s_next)) {
        // Already in the past — we fell behind (usually MIN_STEP_US is too
        // aggressive for the current speed). Give up on catching up silently.
        s_next = make_timeout_time_us(MIN_STEP_US);
        hardware_alarm_set_target((uint)s_alarm, s_next);
    }
}

// d[n] = d[n-1] - (2*d[n-1] + rest) / (4n + 1), carrying the division remainder
// between steps.
//
// The remainder is not an optimisation, it is the whole thing. Without it the
// quotient truncates to zero as soon as 2*d falls below (4n+1) — d stops
// changing, the ramp freezes mid-climb, and the motor tops out at roughly
// (1e6 * accel)^(1/3) steps/s no matter what speed limit was asked for. At
// accel = 8000 that ceiling is about 2000 steps/s, which looks exactly like a
// motor that has run out of torque.
static uint32_t recur(uint32_t d, int32_t n)
{
    int32_t den = 4 * n + 1;                // negative while decelerating
    int32_t num = 2 * (int32_t)d + s_rest;
    s_rest = num % den;
    return (uint32_t)((int32_t)d - num / den);
}

// One recurrence step. Returns false when a deceleration has reached zero.
static bool ramp_next(void)
{
    int32_t  n = s_n;
    uint32_t d = s_d;

    if (n < 0) {
        // Decelerating: 4n+1 is negative, so subtracting the term grows d.
        d = recur(d, n);
        if (++n == 0) {
            s_n = 0;
            return false;
        }
    } else if (d <= s_d_min) {
        // Cruising. n is deliberately frozen here: it holds the height of the
        // ramp we climbed, which is what the deceleration will retrace.
        d = s_d_min;
    } else {
        n++;
        // The recurrence is a poor approximation at n == 1 (it gives 0.6*d0
        // where the true value is 0.4142*d0); AVR446 substitutes 0.4056*d0,
        // which lands the *rest* of the series on the exact curve.
        if (n == 1) {
            d = (uint32_t)((uint64_t)s_d0 * 4056u / 10000u);
            s_rest = 0;
        } else {
            d = recur(d, n);
        }
        if (d < s_d_min)
            d = s_d_min;
    }

    if (d < MIN_STEP_US) d = MIN_STEP_US;
    if (d > MAX_STEP_US) d = MAX_STEP_US;
    s_n = n;
    s_d = d;
    return true;
}

static void finish_from_isr(void)
{
    s_mode = M_IDLE;
    s_n    = 0;
    s_d    = s_d0;
    s_rest = 0;

    TaskHandle_t w = s_waiter;
    if (w) {
        BaseType_t woken = pdFALSE;
        s_waiter = NULL;
        vTaskNotifyGiveFromISR(w, &woken);
        portYIELD_FROM_ISR(woken);
    }
}
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

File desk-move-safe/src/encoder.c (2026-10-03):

//
// encoder_task — polls the MT6835 and accumulates a continuous shaft position.
// See encoder.h.
//
// The sensor wraps at one revolution, so the task takes the difference between
// consecutive samples and folds it into the shorter direction. Nothing here is
// time-critical: the step pulses come out of an alarm ISR and this task only
// observes.
//
#include "encoder.h"
#include "mt6835.h"
#include "limits.h"
#include "board_config.h"

#include "pico/stdlib.h"
#include "FreeRTOS.h"
#include "task.h"

#include <stdio.h>

// Two milliseconds, which is 250 revolutions per second of trackable speed —
// about three orders of magnitude more than the output shaft of a 17:1 reducer
// will ever see. The period is this short so a hand-turned shaft reads smoothly
// on the console, not because the unwrap needs it.
#define ENCODER_PERIOD_MS   2

static volatile int64_t  s_counts;      // continuous, signed, since the last zero
static volatile uint32_t s_late;        // samples that missed their slot
static volatile uint32_t s_jumps;       // samples too big to trust the unwrap
static volatile uint32_t s_weak;        // samples flagged WEAK FIELD
static volatile uint32_t s_samples;     // good samples, so weak can be a fraction
static volatile TickType_t s_weak_at;   // when the last weak one arrived
static volatile bool     s_weak_ever;
static volatile uint8_t  s_status;      // status bits of the last good sample
static volatile bool     s_ok;
static volatile bool     s_zero_req;
static volatile uint32_t s_zero_gen;

static volatile uint32_t s_last;        // previous raw sample, owned by the task

bool     encoder_available(void) { return s_ok; }
uint32_t encoder_errors(void)    { return mt6835_crc_errors(); }
uint32_t encoder_late(void)      { return s_late; }
uint32_t encoder_jumps(void)     { return s_jumps; }
uint32_t encoder_weak(void)      { return s_weak; }
uint32_t encoder_samples(void)   { return s_samples; }

uint32_t encoder_weak_age_ms(void)
{
    if (!s_weak_ever)
        return UINT32_MAX;
    return (uint32_t)((xTaskGetTickCount() - s_weak_at) * portTICK_PERIOD_MS);
}
uint8_t  encoder_status(void)    { return s_status; }
uint32_t encoder_raw(void)       { return s_last; }
uint32_t encoder_zero_gen(void)  { return s_zero_gen; }

// A 64-bit load is two words on Cortex-M33, and this task can preempt a reader
// between them. The critical section makes the copy whole.
int64_t encoder_counts(void)
{
    taskENTER_CRITICAL();
    int64_t c = s_counts;
    taskEXIT_CRITICAL();
    return c;
}

double encoder_degrees(void) { return (double)encoder_counts() * 360.0 / ENCODER_CPR; }
double encoder_revs(void)    { return (double)encoder_counts() / ENCODER_CPR; }

// Starts from the measured value in board_config.h, so the firmware comes up
// knowing its own mechanics. 'enc gear' overrides it for the session.
static double s_gear = GEAR_RATIO;

void encoder_set_gear(double motor_revs_per_output_rev)
{
    if (motor_revs_per_output_rev > 0.0)
        s_gear = motor_revs_per_output_rev;
}

double encoder_gear(void) { return s_gear; }

double encoder_tolerance_deg(void)
{
    // POSITION_TOLERANCE_DEG is a motor-shaft figure — a bit over half a full
    // step — so referring it to the output shaft divides it too.
    double want = POSITION_TOLERANCE_DEG / s_gear;
    return want > ENCODER_NOISE_FLOOR_DEG ? want : ENCODER_NOISE_FLOOR_DEG;
}

void encoder_zero(void)
{
    // Handled in the task so it cannot race the accumulate below.
    s_zero_req = true;
}

void encoder_task(void *arg)
{
    (void)arg;

    if (!mt6835_init())
        printf("[enc] MT6835 not answering on SPI — CS=GP%d SCK=GP%d MOSI=GP%d"
               " MISO=GP%d, 3V3 and GND. Retrying every second.\n",
               MT6835_PIN_CS, MT6835_PIN_SCK, MT6835_PIN_MOSI, MT6835_PIN_MISO);

    // Seed s_last before accumulating, or the first delta is measured against
    // zero and injects a bogus jump of up to half a revolution.
    //
    // Keep retrying: a sensor plugged in later, or one whose lead was loose at
    // boot, comes back without a reset. SPI has no wedged-bus state to clear —
    // every frame starts fresh at the CS edge — so a retry is just another read.
    uint8_t  st = 0;
    uint32_t raw0;
    for (uint32_t tries = 0; !mt6835_angle(&raw0, &st); tries++) {
        vTaskDelay(pdMS_TO_TICKS(1000));
        if (mt6835_init() && tries)
            printf("[enc] MT6835 back after %lu s\n", (unsigned long)tries + 1);
    }
    s_last   = raw0;
    s_status = st;
    s_ok     = true;
    printf("[enc] MT6835 ok, field %s, raw %lu\n",
           mt6835_status_str(st), (unsigned long)s_last);

    TickType_t next = xTaskGetTickCount();
    for (;;) {
        // vTaskDelayUntil does not delay at all when the wake-up it was given
        // is already in the past. Left alone, `next` then falls a tick further
        // behind on every pass and this loop becomes a busy-wait that starves
        // every lower-priority task — the console included. Resync instead, so
        // a late sample costs samples, not the shell.
        TickType_t now = xTaskGetTickCount();
        if ((int32_t)(now - next) > 0) {
            s_late++;
            next = now;
        }
        vTaskDelayUntil(&next, pdMS_TO_TICKS(ENCODER_PERIOD_MS));

        uint32_t raw;
        if (!mt6835_angle(&raw, &st))
            continue;       // CRC failure, counted in the driver. A dropped
                            // sample is not motion, so nothing accumulates.

        s_status = st;
        s_samples++;
        if (st & MT6835_ST_WEAK) {
            s_weak++;
            s_weak_at   = xTaskGetTickCount();
            s_weak_ever = true;
        }

        int32_t d = (int32_t)raw - (int32_t)s_last;
        if (d >  (int32_t)ENCODER_CPR / 2) d -= ENCODER_CPR;    // wrapped backwards
        if (d < -(int32_t)ENCODER_CPR / 2) d += ENCODER_CPR;    // wrapped forwards
        s_last = raw;

        // Everything above rests on the shaft having moved less than half a turn
        // since the last sample. Past that the fold picks the wrong direction
        // and the position is silently, permanently wrong — no bus error, no
        // complaint, just a number that drifts. A quarter turn is the alarm
        // line: still unwrapped correctly, but with no margin left.
        if (d > (int32_t)ENCODER_CPR / 4 || d < -(int32_t)ENCODER_CPR / 4)
            s_jumps++;

        taskENTER_CRITICAL();
        if (s_zero_req) {
            s_zero_req = false;
            s_counts   = 0;
            s_zero_gen++;
        } else {
            s_counts += d;
        }
        taskEXIT_CRITICAL();

        // Every sample also goes past the travel guard. A few integer ops; it
        // hard-stops the motor if the shaft has left the calibrated range.
        limits_guard(raw);
    }
}

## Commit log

2026-10-02 desk-move-safe: production firmware, docs, wiring and printed parts
    Production firmware for the CL103B-G standing desk (RP2350/FreeRTOS): sits in
    the cut panel-TX wire, proxies keys to the main board, enforces the ceiling and
    stops the desk at the flap height. Includes the protocol and wiring docs, the
    3D-printed parts and the laptop-side UART tools. The desk-lab bench rig stays
    local.
    The console 'go' now hands its move to flap_task through the flap job slot,
    so the bus is in ST_MOVING and the UP/DOWN key is actually transmitted. It
    also no longer blocks the console, and 'stop' no longer leaves it dead.
    [angle-sensor-holder.scad, angle-sensor-holder.stl, encoder-holder.3mf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]
2026-10-02 desk-move-safe: flap calibration, desk lock, eeprom params, debug trace
    Flap travel limits ported from the bench rig (limits.c) and stored in the
    shared settings record. Without an answering MT6835 and a stored min/max the
    desk is locked: every panel move is refused and the onboard WS2812 blinks red.
    'init' calibrates step by step (jog to min, done, jog to max, done); 'reset'
    clears exactly the six calibration parameters.
    Console reorganised: a few top-level words (status, init, done, abort, stop,
    dev, eeprom, go, reset, ?) and groups (desk, debug, lim, mot, tmc, enc). Stored
    values are read and set with 'eeprom [<name>] | eeprom set <name> <value>',
    named <group>_<field>. Motor speed is no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
    [board_config.h, bus.c, console.c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]
2026-10-02 desk-move-safe: real flap move, manual crossings, crossing guard, ceiling taps
    The flap now moves for real: collapsed above the flap height, expanded below,
    driven through the travel limits and settled under the encoder. If it does not
    get there the desk stays put. Flap ends renamed min/max -> expanded/collapsed;
    'init' renamed 'calibrate'; 'reset' is always available.
    New stored parameters:
    - mot_early_start: start the flap as the desk is told to stop (overlapping the
    coast) instead of once it has stopped.
    - desk_early_resume: re-send the recall once the flap's fast part is over and
    the encoder puts it within reach of its end, instead of after the creep.
    Manual moves (held UP/DOWN, si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
    [board_config.h, console.c, flap.c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]
2026-10-03 desk-move-safe: encoder-steered flap, desk_resume_pct, recall-to-still-desk
    The flap's calibration is now just the two encoder angles plus two signs
    (lim_enc_dir: which way round, lim_mot_dir: which way the motor collapses
    it, learned by watching the encoder). lim_enc_span, lim_span_steps,
    lim_steps_per_rev, 'lim span' and 'lim sync' are gone; a stored record is
    converted in place from the old values' signs, so no recalibration.
    Moves are steered by the encoder: the motor runs towards the target and the
    encoder task ramps it down lim_approach_deg short, from the remaining
    distance and the braking distance at the present speed; the creep finishes.
    A miscounted span or lost steps can no longe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
    [bus.c, console.c, encoder.c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]
